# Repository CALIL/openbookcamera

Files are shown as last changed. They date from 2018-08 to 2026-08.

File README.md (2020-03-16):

# Open Book Camera v1

汎用的なデバイスで構成される高速な書影撮影システム

## コンセプト

- 書影（本の表示画像）キャプチャ用のスキャナデバイス
- 本を置いたら自動撮影
- 表紙・裏表紙・背の3面を高速撮影（2秒程度）
- ネットワーク接続なしでスタンドアロン動作

## システム構成

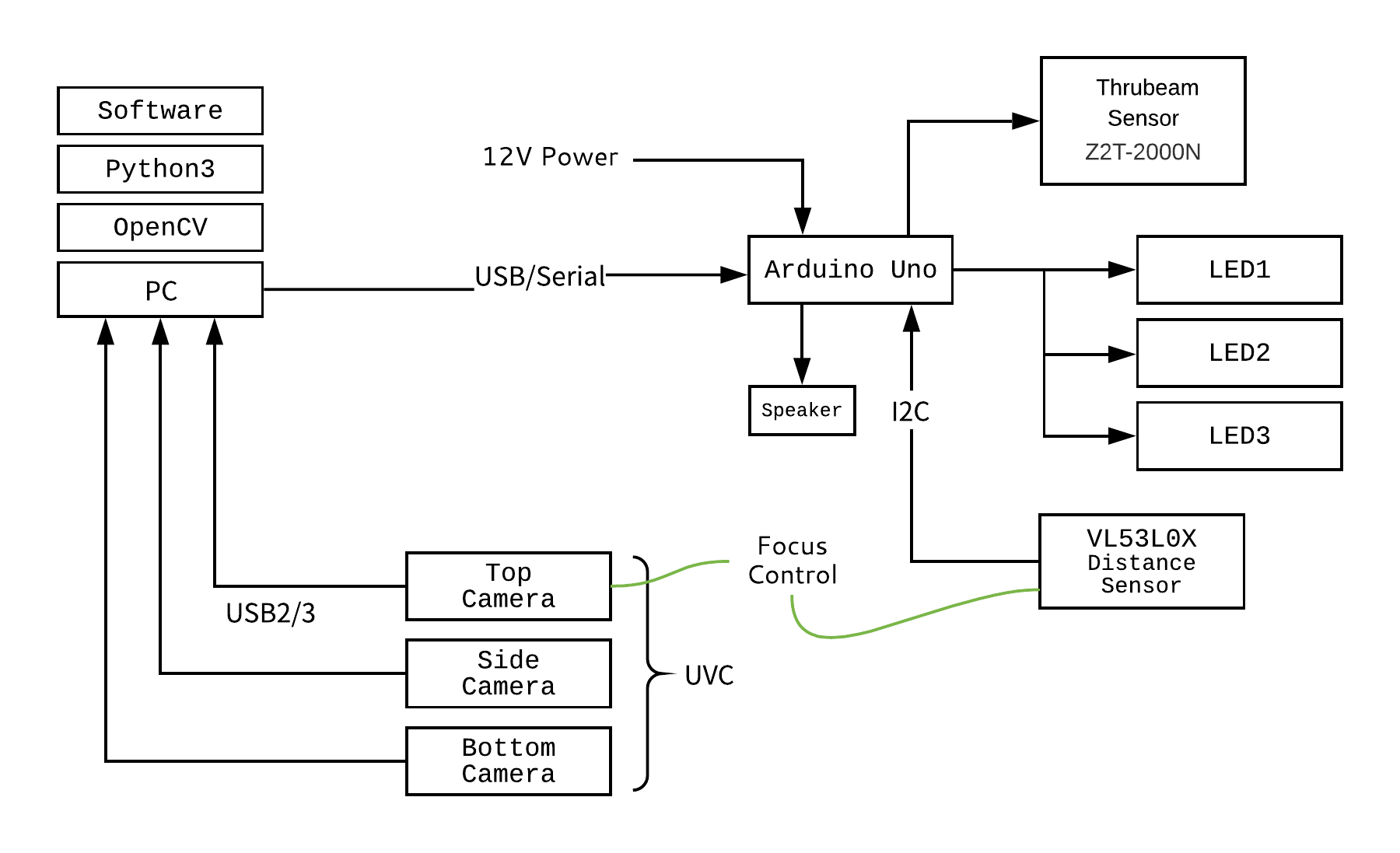
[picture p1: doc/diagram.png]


## Installation

Windows:

- [Anaconda](https://www.anaconda.com/download/) Python3.7 をインストール
- [libjpeg-turbo](https://libjpeg-turbo.org/Documentation/Documentation) をインストール [libjpeg-turbo-1.5.3-vc64.exe](https://sourceforge.net/projects/libjpeg-turbo/files/1.5.3/libjpeg-turbo-1.5.3-vc64.exe/download)
- [Visual C++ Redistributable Packages for Visual Studio 2013](https://www.microsoft.com/en-US/download/details.aspx?id=40784)をインストール（pyzbarが依存）

```sh
conda install opencv==3.4.2
pip install -r requirements.txt
python capture.py
```

## キーボード操作

| キー | 役割 |
|---|---|
| 0 | コントローラーリセット |
| 1 | 上面のカメラに切り替える |
| 2 | 下面のカメラに切り替える |
| 3 | 背面のカメラに切り替える |
| 4 | 距離センサのテスト |
| c | カメラの設定画面を開く |
| ESC  | システム終了 |
| Enter| 手動撮影 |

1→c 2→c と操作することで各カメラの設定を順次調整できます。調整結果は保存されません。

## 制御ボード

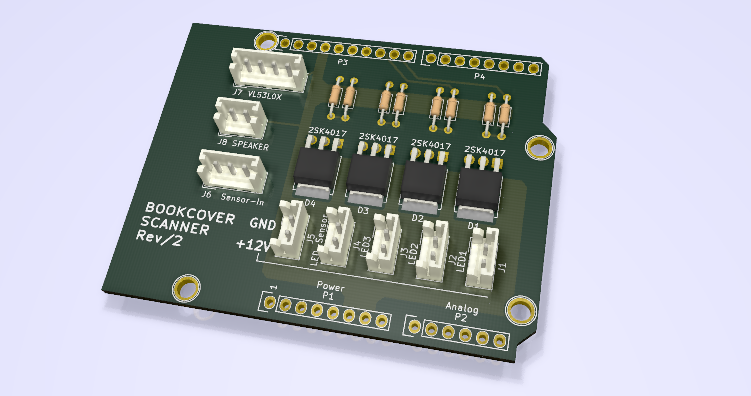
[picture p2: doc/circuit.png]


- Arudinoシールド互換サイズ
- MOSFETによる12V制御回路×4
- 各種センサ向けのコネクタ（2.5mmピッチ・XHシリーズ）
- [Pololu Arduino library for VL53L0X](https://github.com/pololu/vl53l0x-arduino)
- 光電センサ [Z2T-2000N](https://www.optex-fa.jp/products/photo_sensor/amp/z_eco/index.html) を本が置かれたことを検出するセンサとして採用

## UVCカメラ

- [UVC規格](https://en.wikipedia.org/wiki/USB_video_device_class)の汎用的なUSBカメラに対応
- カーリルでは[IPEVO社製V4K](https://www.ipevo.jp/v4k.html)を採用（800万画素）
- 各カメラを独立したUSBポートに接続すること（USBハブを用いた場合は帯域不足となる）

## 注意事項

- 輸送後にはフォーカス設定が変動する場合があります。最適な画質になる設定にソースコードを調整してください。
- 2019年12月購入以降のV4Kにおいて、色温度の設定が自動化できない不具合を確認しています。この問題は[openCV側の不具合](https://github.com/opencv/opencv/issues/13130)の可能性があります。cコマンドによるマニュアル設定をお願いします。
 
## Release History

* 0.0.1 Work in progress
* 1.0.0 正式リリース
* 1.1.0 V4K最新ファームウェアに対応
* 1.2.0 V4K最新ファームウェアに対応

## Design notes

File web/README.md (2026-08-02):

# OpenBookCamera Web Site

https://openbookcamera.com

ビルドの無い静的サイトです。`index.html` / `css/style.css` / `img/` をそのまま配信しています。

## Development

このディレクトリのファイルを直接編集してください。確認はブラウザで `index.html` を開くだけです。

以前は sass を Parcel でビルドしていましたが、1ページの静的サイトに
ビルドを挟む必要が無いため廃止しました。CSS は `css/style.css` が原本です。

## Deploy

https://dash.cloudflare.com/9f2a842113dbb9618c3d37c24fa23af4/pages/view/openbookcamera

master にコミットすると Cloudflare Pages に配信されます。ビルドは走りません。

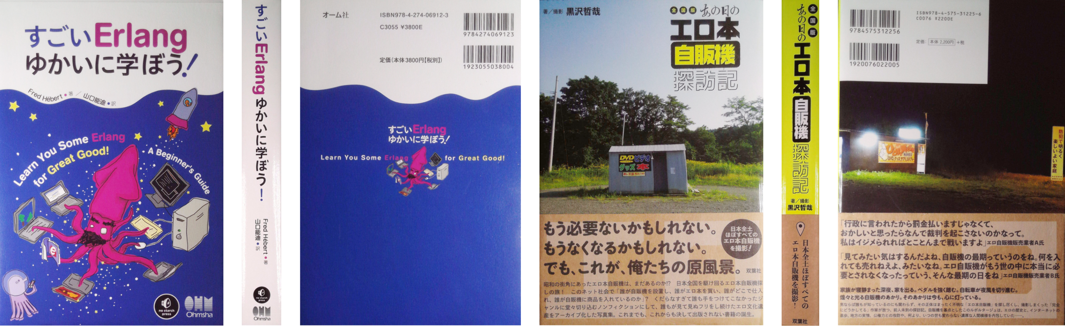
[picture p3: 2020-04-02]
web/img/cover@2x.png

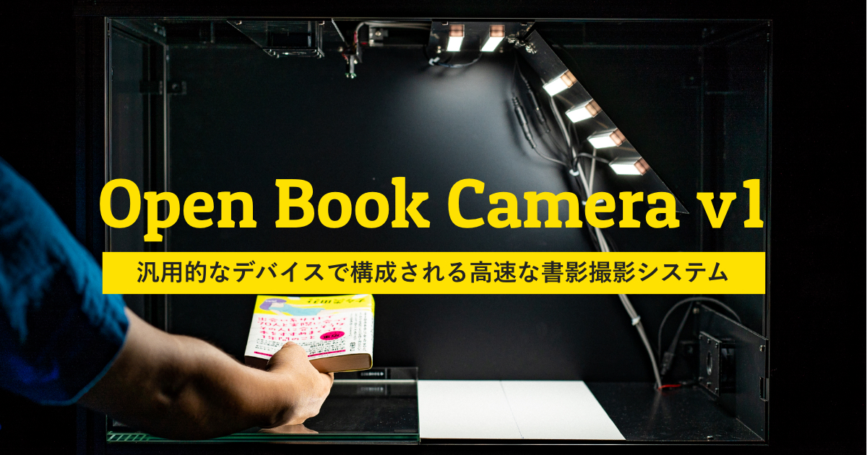
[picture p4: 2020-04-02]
web/img/og-image.jpg

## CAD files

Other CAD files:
parts/camera-braket-side.dwg
parts/camera-braket-top-bottom.dwg
parts/distanse-sensor-braket.dwg
parts/glass-fitting-1.dwg
parts/camera-braket.dwg
parts/controller-attachment.dwg

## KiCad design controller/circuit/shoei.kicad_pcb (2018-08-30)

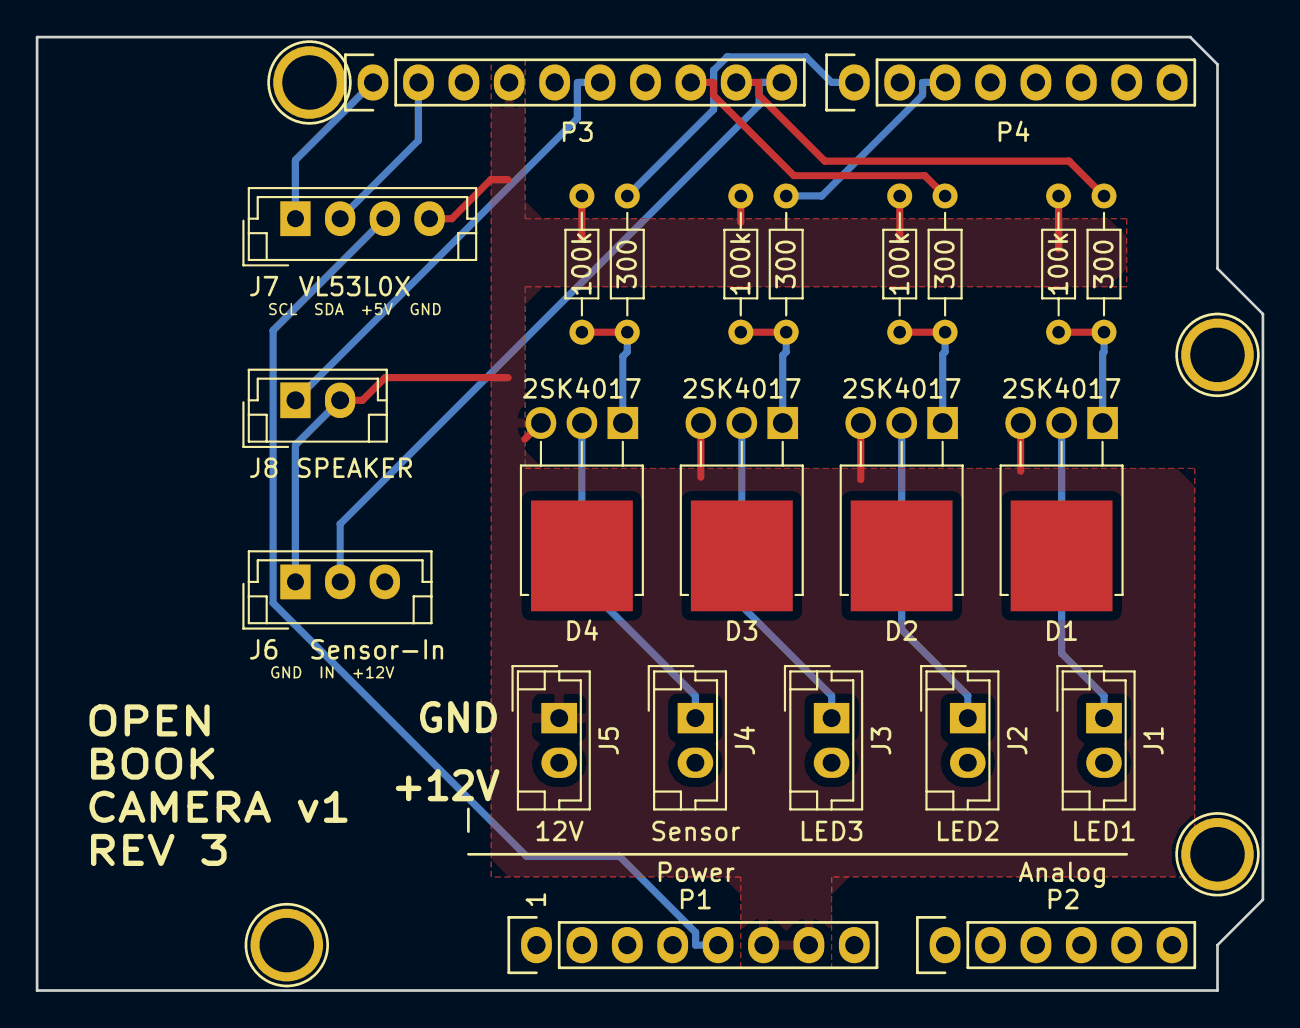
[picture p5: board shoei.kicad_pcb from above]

Board: 2 copper layers, 68.6 x 53.3 mm, 28 parts (0 on the bottom side), 19 nets.

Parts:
D1, D2, D3, D4: 2SK4017; TO-251-3-1EP_Horizontal_TabDown
J1: LED1; JST_EH_B02B-EH-A_1x02_P2.50mm_Vertical
J2: LED2; JST_EH_B02B-EH-A_1x02_P2.50mm_Vertical
J3: LED3; JST_EH_B02B-EH-A_1x02_P2.50mm_Vertical
J4: Sensor; JST_EH_B02B-EH-A_1x02_P2.50mm_Vertical
J5: 12V; JST_EH_B02B-EH-A_1x02_P2.50mm_Vertical
J6: Sensor-In; JST_EH_B03B-EH-A_1x03_P2.50mm_Vertical
J7: VL53L0X; JST_EH_B04B-EH-A_1x04_P2.50mm_Vertical
J8: SPEAKER; JST_EH_B02B-EH-A_1x02_P2.50mm_Vertical
P1: Power; Socket_Strip_Arduino_1x08
P2: Analog; Socket_Strip_Arduino_1x06
P3: Digital; Socket_Strip_Arduino_1x10
P4: Digital; Socket_Strip_Arduino_1x08
P5, P6, P7, P8: CONN_01X01; Arduino_1pin
R1, R2, R3, R4: 300; R_Axial_DIN0204_L3.6mm_D1.6mm_P7.62mm_Horizontal
R5, R6, R7, R8: 100k; R_Axial_DIN0204_L3.6mm_D1.6mm_P7.62mm_Horizontal

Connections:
+5V: J7.3, P1.5
+12V: J1.2, J2.2, J3.2, J4.2, J5.2, J6.3, P1.8
/5(**): P4.3, R3.1
/7: P4.1, R4.1
/8: J6.2, P3.10
/9(**): P3.9, R1.1
/10(**/SS): P3.8, R2.1
/12(MISO): J8.1, P3.6
/A4(SDA): J7.2, P3.2
/A5(SCL): J7.1, P3.1
GND: D1.3, D2.3, D3.3, D4.3, J5.1, J6.1, J7.4, J8.2, P1.6, P1.7, P3.4, R5.2, R6.2, R7.2, R8.2
unnamed: D1.1, R1.2, R5.1
unnamed: D1.2, J1.1
unnamed: D2.1, R2.2, R6.1
unnamed: D2.2, J2.1
unnamed: D3.1, R3.2, R7.1
unnamed: D3.2, J3.1
unnamed: D4.1, R4.2, R8.1
unnamed: D4.2, J4.1

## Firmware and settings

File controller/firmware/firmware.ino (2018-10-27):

/**
  BOOK-COVER-SCANNER phy-modu]le

  Copyright (c) 2018 Ryuuji Yoshimoto

  This software is released under the MIT License.
  http://opensource.org/licenses/mit-license.php
*/

#include <Wire.h>
#include <VL53L0X.h>

VL53L0X sensor;

const int SENSOR_ACTIVE_PIN = 7;
const int SENSOR_IN_PIN = 8;
const int SPEAKER_PIN = 12;
const int LED1PIN = 9;
const int LED2PIN = 10;
const int LED3PIN = 5;

int mm = 0;
int inByte = 0;
int currentStatus = 0;
int newStatus = 0;
int eventStatus = -1;
unsigned long eventStarted = 0;
unsigned long ignoreMillis = 0;

void setup() {
  pinMode(SPEAKER_PIN, OUTPUT);
  pinMode(LED_BUILTIN, OUTPUT);
  pinMode(LED1PIN, OUTPUT);
  pinMode(LED2PIN, OUTPUT);
  pinMode(LED3PIN, OUTPUT);
  pinMode(SENSOR_ACTIVE_PIN, OUTPUT);
  pinMode(SENSOR_IN_PIN, INPUT_PULLUP);
  digitalWrite(LED_BUILTIN, LOW);
  digitalWrite(LED1PIN, LOW);
  digitalWrite(LED2PIN, LOW);
  digitalWrite(LED3PIN, LOW);
  digitalWrite(SENSOR_ACTIVE_PIN, LOW);
  Serial.begin(115200);
  Wire.begin();
  sensor.init();
  sensor.setTimeout(500);
  sensor.setMeasurementTimingBudget(200000);
  sensor.setSignalRateLimit(0.1);
  sensor.setVcselPulsePeriod(VL53L0X::VcselPeriodPreRange, 18);
  sensor.setVcselPulsePeriod(VL53L0X::VcselPeriodFinalRange, 14);
  while (!Serial) {
    ;
  }
}

void ranging() {
  mm = 384 - sensor.readRangeSingleMillimeters();
  if (mm < 0) {
    mm = 0;
  }
  if (sensor.timeoutOccurred()) {
    Serial.print("HEIGHT:TIMEOUT");
  } else {
    Serial.print("HEIGHT:");
    Serial.print(mm);
  }
  Serial.println();
}

void loop() {
  if (Serial.available() > 0) {
    inByte = Serial.read();
    if (inByte == '1') {
      tone(SPEAKER_PIN, 500, 20);
      digitalWrite(LED_BUILTIN, HIGH);
      digitalWrite(LED1PIN, LOW);
      digitalWrite(LED2PIN, HIGH);
      digitalWrite(LED3PIN, LOW);
      digitalWrite(SENSOR_ACTIVE_PIN, LOW);
    }
    if (inByte == '2') {
      tone(SPEAKER_PIN, 600, 130);
      digitalWrite(LED_BUILTIN, LOW);
      digitalWrite(LED1PIN, HIGH);
      digitalWrite(LED2PIN, LOW);
      digitalWrite(LED3PIN, LOW);
      digitalWrite(SENSOR_ACTIVE_PIN, LOW);
    }
    if (inByte == '3') {
      //tone(SPEAKER_PIN, 600, 130);
      digitalWrite(LED_BUILTIN, LOW);
      digitalWrite(LED1PIN, HIGH);
      digitalWrite(LED2PIN, HIGH);
      digitalWrite(LED3PIN, HIGH);
      digitalWrite(SENSOR_ACTIVE_PIN, HIGH);
      ignoreMillis = millis();
    }
    if (inByte == '4') {
      tone(SPEAKER_PIN, 300, 100);
      digitalWrite(LED_BUILTIN, HIGH);
      digitalWrite( LED1PIN, HIGH);
      digitalWrite( LED2PIN, HIGH);
      digitalWrite( LED3PIN, HIGH);
      digitalWrite(SENSOR_ACTIVE_PIN, LOW);
      ranging();
    }
    if (inByte == '0') {
      digitalWrite(LED_BUILTIN, LOW);
      digitalWrite(LED1PIN, LOW);
      digitalWrite(LED2PIN, LOW);
      digitalWrite(LED3PIN, LOW);
      digitalWrite(SENSOR_ACTIVE_PIN, LOW);
    }
    Serial.println("ACK");
  }
  if (bitRead(PORTD, SENSOR_ACTIVE_PIN) == 1) {
    newStatus = digitalRead(SENSOR_IN_PIN);
    if (currentStatus != newStatus) {
      if (eventStatus == -1 || eventStatus != newStatus) {
        if (newStatus == 0) {
          tone(SPEAKER_PIN, 400, 20);
        }
        eventStatus = newStatus;
        eventStarted = millis();
      } else {
        if (eventStatus == 1 && newStatus == 1) {
          if (millis() - eventStarted > 300) {
            currentStatus = 1;
            eventStatus = -1;
            if (millis() - ignoreMillis > 500) {
              Serial.println("LEAVE");
            } else {
              Serial.println("SKIP");
            }
          }
        } else if (eventStatus == 0 && newStatus == 0) {
          if (millis() - eventStarted > 1500) {
            currentStatus = 0;
            eventStatus = -1;
            if (millis() - ignoreMillis > 2000) {
              Serial.println("ON");
            } else {
              Serial.println("SKIP");
            }
          }
        }
      }
    } else {
      eventStatus = -1;
    }
  }
}

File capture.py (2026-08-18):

import serial
import cv2
import numpy as np
import time
import datetime
import os
import json
import platform
import logging
import coloredlogs
from turbojpeg import TurboJPEG

DATAPATH = os.path.normpath(
    os.path.join(os.path.dirname(os.path.abspath(__file__)), "./data/")
)
IS_NEW4K = True  # 新しいV4Kファームウェア（製造番号10以下ではFalseを指定）

logger = logging.getLogger("システム")
coloredlogs.install(level="DEBUG", fmt="%(asctime)s %(levelname)s %(message)s")
jpeg = TurboJPEG()


def barcode_recognition(images):
    from pyzbar.pyzbar import decode
    from pyzbar.pyzbar import ZBarSymbol

    rs = []
    for image, role in images:
        result = decode(image, symbols=[ZBarSymbol.EAN13, ZBarSymbol.CODABAR])
        for item in result:
            r = {
                "role": role,
                "data": item.data.decode("utf-8"),
                "type": item.type,
                "rect": {
                    "left": item.rect.left,
                    "top": item.rect.top,
                    "width": item.rect.width,
                    "height": item.rect.height,
                },
                "polygon": [],
            }
            for p in item.polygon:
                r["polygon"].append({"x": p.x, "y": p.y})
            rs.append(r)
    return rs


def connect_controller():
    ser = None
    for port in range(1, 10):
        try:
            ser = serial.Serial("COM%d" % port, 115200, timeout=1, write_timeout=1)
            logger.debug("COM%dに接続中..." % port)
            for _ in range(1, 5):
                if ser.in_waiting > 0:
                    ser.read_all()
                ser.write(b"3")
                ser.flush()
                ser.write(b"3")
                ser.flush()
                time.sleep(0.5)
                if ser.in_waiting > 0:
                    line = ser.readline().strip().decode("utf-8")
                    if line == "ACK":
                        return ser
            ser.close()
        except serial.serialutil.SerialException:
            pass
    return None


def calc_white_region(img):
    """
    画像上部(20ピクセル)の白領域の割合を返す
    """
    im = img[0:20, :]
    im = cv2.cvtColor(im, cv2.COLOR_BGR2GRAY)
    _, im = cv2.threshold(im, 0, 255, cv2.THRESH_BINARY + cv2.THRESH_OTSU)
    hist = cv2.calcHist([im], [0], None, [2], [0, 256])
    return hist[1][0] / (hist[0][0] + hist[1][0])


def write_jpeg(filename, image):
    with open(filename, "wb") as f:
        f.write(jpeg.encode(image))


logger.info("制御装置に接続しています")
ser = connect_controller()
if not ser:
    logger.error("制御装置に接続できませんでした")
    input()
    exit()
logger.info("制御装置に接続しました")


def initialize_camera(cap, role):
    logger.info("カメラ[%s]を初期化しています" % role)

    if IS_NEW4K:
        # しばらく低解像度をデータ取得した後に、高解像度に切り替える
        cap.set(cv2.CAP_PROP_AUTO_EXPOSURE, 0.25)
        cap.set(cv2.CAP_PROP_EXPOSURE, float(-6))
        cap.set(cv2.CAP_PROP_FPS, 15)
        cap.set(cv2.CAP_PROP_FRAME_WIDTH, 640)
        cap.set(cv2.CAP_PROP_FRAME_HEIGHT, 480)
        cap.set(cv2.CAP_PROP_FOURCC, cv2.VideoWriter_fourcc('M', 'J', 'P', 'G'))
        for x in range(1, 50):
            cap.read()

    cap.set(cv2.CAP_PROP_FPS, 15)
    cap.set(cv2.CAP_PROP_FRAME_HEIGHT, 2448)
    cap.set(cv2.CAP_PROP_FRAME_WIDTH, 3264)
    for x in range(1, 5):
        cap.read()

    cap.set(cv2.CAP_PROP_AUTOFOCUS, 0)  # オートフォーカスオフ

    if IS_NEW4K:
        cap.set(cv2.CAP_PROP_WHITE_BALANCE_BLUE_U, 5000)  # 色温度（反映されない: https://github.com/opencv/opencv/issues/13130）
    else:
        cap.set(cv2.CAP_PROP_WHITE_BALANCE_BLUE_U, 6000)  # 色温度

    cap.set(cv2.CAP_PROP_SHARPNESS, 2)
    cap.set(cv2.CAP_PROP_SATURATION, 64)
    cap.set(cv2.CAP_PROP_HUE, 0)
    if role == "BOTTOM":
        cap.set(cv2.CAP_PROP_FOCUS, 271 if IS_NEW4K else 112)
        cap.set(cv2.CAP_PROP_BRIGHTNESS, 0 if IS_NEW4K else -50)
        cap.set(cv2.CAP_PROP_GAMMA, 110 if IS_NEW4K else 150)
        if IS_NEW4K:
            cap.set(cv2.CAP_PROP_AUTO_EXPOSURE, 0.25)
            cap.set(cv2.CAP_PROP_EXPOSURE, float(-7))
    elif role == "SIDE":
        cap.set(cv2.CAP_PROP_FOCUS, 235 if IS_NEW4K else 95)  # フォーカス設定
        cap.set(cv2.CAP_PROP_BRIGHTNESS, 0 if IS_NEW4K else -100)
        cap.set(cv2.CAP_PROP_GAMMA, 110 if IS_NEW4K else 110)
        if IS_NEW4K:
            cap.set(cv2.CAP_PROP_AUTO_EXPOSURE, 0.25)
            cap.set(cv2.CAP_PROP_EXPOSURE, float(-7))
    elif role == "TOP":
        cap.set(cv2.CAP_PROP_FOCUS, 200 if IS_NEW4K else 77)  # フォーカス設定
        cap.set(cv2.CAP_PROP_BRIGHTNESS, 0 if IS_NEW4K else -40)
        cap.set(cv2.CAP_PROP_GAMMA, 110 if IS_NEW4K else 130)
        if IS_NEW4K:
            cap.set(cv2.CAP_PROP_AUTO_EXPOSURE, 0.25)
            cap.set(cv2.CAP_PROP_EXPOSURE, float(-6))
    else:
        cap.set(cv2.CAP_PROP_FOCUS, 200 if IS_NEW4K else 70)
        cap.set(cv2.CAP_PROP_BRIGHTNESS, 0 if IS_NEW4K else -40)
        cap.set(cv2.CAP_PROP_GAMMA, 100)
        if IS_NEW4K:
            cap.set(cv2.CAP_PROP_AUTO_EXPOSURE, float(1))


cameras = []
for x in range(0, 3):
    cameras.append(cv2.VideoCapture(x + 700))
    initialize_camera(cameras[x], str(x + 1))

logger.info("カメラの起動を待っています")
time.sleep(3)

white_regions = []
for x in range(0, 3):
    logger.info("カメラ[%d]の撮影テスト中..." % (x + 1))
    err, img = cameras[x].read()
    r = calc_white_region(img)
    logger.info("ホワイト領域比率:%0.2f" % r)
    white_regions.append((r, x))

# 白領域がないカメラが側面
white_regions = sorted(white_regions)
index_side = white_regions[0][1]
index_top = None
index_bottom = None
logger.info("カメラ[SIDE]を検出しました:%d" % (index_side + 1))

# 上照明のみに切り替える
logger.info("残りのカメラをテスト中...")
ser.write(b"1")
while True:
    _, img1 = cameras[white_regions[1][1]].read()
    r1 = calc_white_region(img1)
    _, img2 = cameras[white_regions[2][1]].read()
    r2 = calc_white_region(img2)
    if abs(r1 - r2) > 0.3:
        if r1 > r2:
            logger.info("カメラ[TOP]を検出しました:%d" % (white_regions[1][1] + 1))
            index_top = white_regions[1][1]
            index_bottom = white_regions[2][1]
        else:
            logger.info("カメラ[TOP]を検出しました:%d" % (white_regions[2][1] + 1))
            index_top = white_regions[2][1]
            index_bottom = white_regions[1][1]
        break

ser.write(b"3")
cap_top = cameras[index_top]
initialize_camera(cap_top, "TOP")
cap_bottom = cameras[index_bottom]
initialize_camera(cap_bottom, "BOTTOM")
cap_side = cameras[index_side]
initialize_camera(cap_side, "SIDE")

cap_top.grab()
cap_bottom.grab()
cap_side.grab()

role = "SIDE"
stage = 0
mm = None
stock_side1 = None
stock_side2 = None
stock_side3 = None
stock_top = None
stock_bottom = None

logger.info("動作を開始しました")
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

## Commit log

2018-08-17 add circuit board (KiCad)
    [shoei.kicad_pcb, shoei.sch]
2018-08-18 fix lunch check process
    [capture.py]
2018-08-25 update enclosure
2018-08-30 update pcb silk
    [shoei.kicad_pcb]
2018-10-01 add controller-attachment
2018-11-06 update parts
    [camera-braket.dwg, controller-attachment.dwg, distanse-sensor-braket.dwg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]
2019-05-06 update（opencvの最新版でフォーカスが調整できなくなる問題に対応）
    [camera-braket-side.dwg]
2019-05-06 図面を追加
    [camera-braket-side.dwg, camera-braket-top-bottom.dwg]
2019-10-10 新しいV4Kファームウェアに対応 ビデオキャプチャでDirectShowを明確に指定
2019-10-10 ドキュメントを更新
2020-03-16 V4K最新ファームウェアに対応
2020-03-16 上下カメラの認識率を改善
2020-03-16 ドキュメントを追加
2026-03-12 fix(web): cssnanoのバージョンを4.1.10から7.1.3に更新
    - web/package.jsonのdevDependencies内でcssnanoのバージョンを4.1.10から7.1.3に変更しました。
2026-03-12 fix(web): cssnanoのバージョンを4.1.10に戻す
    devDependenciesのcssnanoのバージョンを4.1.10に変更しました。
2026-03-12 feat: package.jsonの更新
    - "main"フィールドを削除しました。
    - "build"スクリプトのオプションを変更し、"--out-dir"を"--dist-dir"に修正しました。
    - "devDependencies"を更新し、"cssnano"と"parcel-bundler"を削除し、"@parcel/transformer-sass"と"parcel"を追加しました。
2026-03-12 fix: GitHub Actionsのcheckoutとデプロイアクションのバージョンを更新
    - actions/checkoutをv2.3.1からv4に更新
    - JamesIves/github-pages-deploy-actionを4.1.1からv4に更新
2026-05-13 ci: npm install/ciに--ignore-scriptsを追加
2026-05-21 chore: npm install → npm ci --ignore-scripts in .github/workflows/gh-pages.yml
2026-05-21 fix: Dependabotバージョンアップデートを無効化（セキュリティのみ有効）
2026-08-01 chore(ci): Dependabot 設定を見直し
    - minor/patch をグループ化し major は個別 PR に分離
    - cooldown を設定しリリース直後の更新を避ける
    - 対象: github-actions, npm, pip
2026-08-01 chore(ci): Actions/Terraform のグループを minor・patch に限定
    update-types を省略すると major もグループに含まれてしまい、
    「major は個別 PR で判断する」という方針と食い違っていた。
    なお semver-major-days は github-actions / docker / terraform では
    サポートされていないため、cooldown 側は変更していない。
2026-08-01 fix(ci): 作業ブランチへの push で GitHub Pages が更新されてしまう問題を修正
    on: [push] はブランチを限定していないため、作業ブランチに push した
    だけで本番への配信が実行される。対象を master に限定する。
2026-08-01 fix(ci): Actionsのセキュリティチェックで指摘された箇所を修正
    - サードパーティ Action を SHA 固定 1箇所
2026-08-01 fix(ci): Actionsのセキュリティチェックの指摘を修正
    zizmorの指摘に基づき、GitHub Pagesデプロイの権限を必要最小限に
    絞り込み、checkoutの認証情報persistを無効化した。
2026-08-01 chore(ci): GitHub Pages の配信を公式 Action 方式へ移行
    gh-pages ブランチへ push する方式(JamesIves)から、公式の
    configure-pages / upload-pages-artifact / deploy-pages へ変える。
    サードパーティ依存が減り、contents: write が不要になる。
    ビルド手順は変更していない。
    マージ後にリポジトリの Pages 設定を GitHub Actions へ切り替える。
2026-08-01 chore(ci): 不要な configure-pages を外す
    configure-pages の役割は静的サイトジェネレータの base path 自動設定と
    Pages サイト情報の取得だが、このリポジトリは base path をソース側で
    指定しており、出力(base_path 等)も参照していないため何もしていない。
    あわせて、このアクションのために付けていた pages: read も外す。
2026-08-01 ci: Actionsのセキュリティチェックを追加する
    zizmor でワークフロー自体のセキュリティ上の問題を検査する。
    .github/ 配下の変更があったときだけ走る。
    判定方針は .github/zizmor.yml に書き下す。GitHub 公式(actions/*)と
    自社(CALIL/*)はタグ指定を許容し、第三者のアクションはコミットSHA固定を必須とする。
2026-08-02 ビルドに使う Node のバージョンを固定する（予防） (#26)
    * fix(build): ビルドに使う Node のバージョンを固定する
    reform で Cloudflare Pages のビルドが Node 12.18.0（Build Image v1 の既定）
    で実行されて失敗していた。このリポジトリも同じ構成で、Node の指定が
    どこにも無いため同じ問題が起きうる。
    依存が要求する Node:
    sass@1.102.0 >=20.19.0
    chokidar@5.0.0 >= 20.19.0
    readdirp@5.0.0 >= 20.19.0
    いまは動いているが、Build Image の既定が変わるか依存が上がると壊れる。
    web/.node-version と engines.node で明示的に固定しておく。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
2026-08-02 web をビルドの無い静的サイトにする (#27)
    1ページの静的サイトに Parcel のビルドを挟む必要が無かったので、
    コンパイル済みの CSS を直接置く形にした。
    ## ビルドの廃止
    sass の中身は 260 行で、変数1つとメディアクエリ用のミックスインだけ。
    コンパイル結果の CSS を web/css/style.css として置けば足りる。
    - Parcel と sass を削除（package.json ごと）
    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
2026-08-02 存在しないパスに 404 を返すようにする (#28)
    Cloudflare Pages は 404.html が無いと、どのパスに対しても
    index.html を HTTP 200 で返す。存在しないページが「見つかった」ことに
    なってしまうため、404.html を置いて正しく 404 を返すようにする。
    このページはどの階層のパスに対しても返されるので、
    アセットの参照は相対パスではなく絶対パスにしている。
    見た目はサイトの配色（#222222 / #FEE100）と Patua One に合わせ、
    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
2026-08-18 chore: ruff の安全な自動修正を当てる
    ruff 0.16.3 の**安全な自動修正だけ**を当てた（`ruff check --fix`、unsafe な修正は適用していない）。
    **修正 5件**: `UP018:4 UP009:1`
    **検証**: 変更した Python ファイル 1件のうち、**0件は AST が完全に一致**する（パース結果が変わらないことを機械的に確認した）。残る 1件は差分を目で見て確認した。全ファイルが構文エラー無しでパースできる。
    このリポジトリは pyproject.toml を持たず、README も Anaconda の Python 3.7 を前提に書かれている。そのため **target-version は ruff の既定（py39）のまま**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
    [capture.py]
